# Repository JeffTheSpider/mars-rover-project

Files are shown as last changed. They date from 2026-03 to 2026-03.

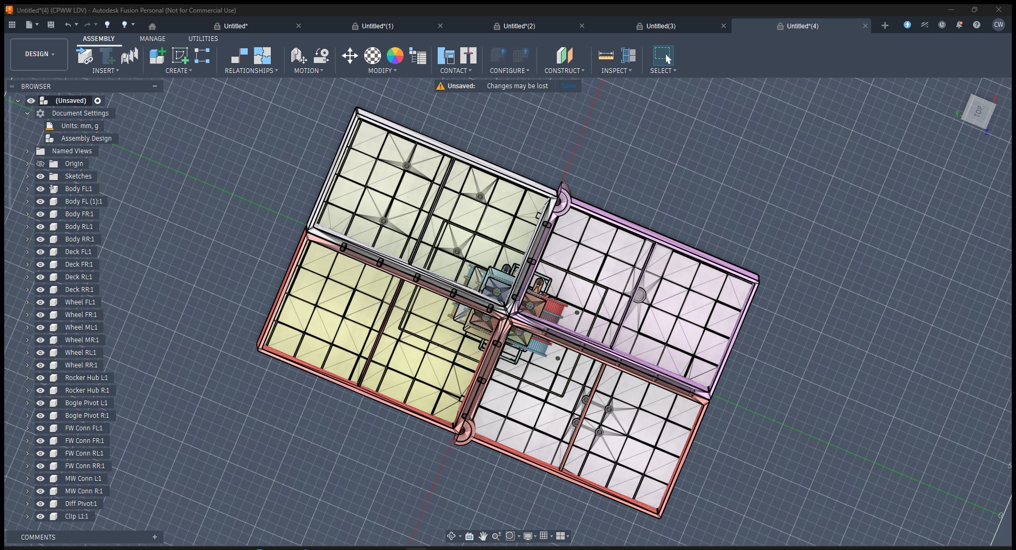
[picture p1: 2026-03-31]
3d-print/assembly_screenshot.png

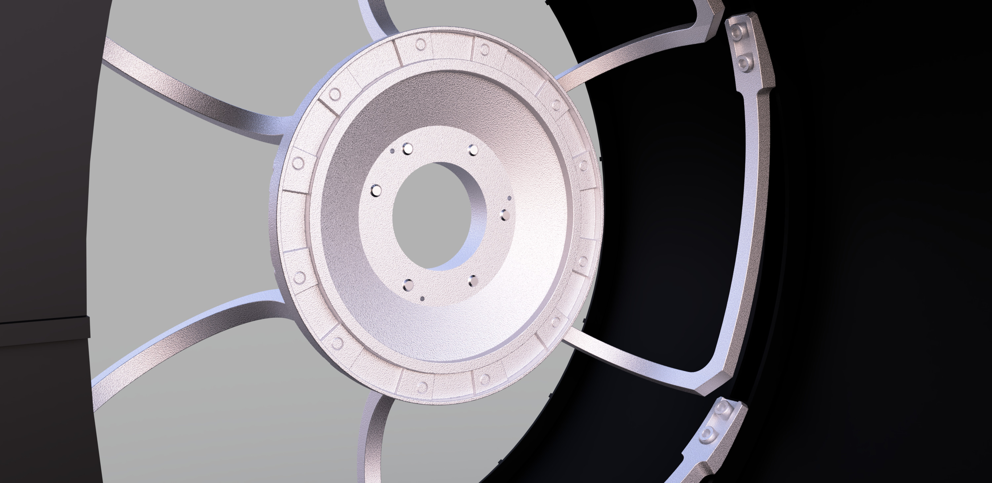
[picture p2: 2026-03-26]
cad/reference-wheels/curiosity-mars-rover-wheel-1.snapshot.2/Curiosity_Wheel_2022-Nov-08_01-30-11PM-000_CustomizedView27291791203.jpg

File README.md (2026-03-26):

# Mars Rover Garden Robot

A Mars rover-inspired outdoor robot designed for garden and park use. Features NASA-style rocker-bogie suspension, 4-wheel Ackermann steering, AI-powered autonomous navigation, and phone-based WebSocket control.

**Current status:** Phase 1 design complete. 23 print-ready STL files exported. Firmware compiles. Ready to print and build.






---

## What Is This?

A 440x260mm (0.4 scale) 3D-printed Mars rover prototype with:
- **6 wheels** with individual N20 motors
- **4-wheel steering** (Ackermann geometry, point turn, crab walk)
- **Rocker-bogie suspension** using 9x 608ZZ bearings and 8mm steel rods
- **ESP32-S3** brain with WiFi control from a phone app
- **Phone PWA** for driving, camera view, telemetry, and mission planning

Phase 1 is a working proof-of-concept. Phase 2 adds a Jetson Orin Nano for autonomous navigation with ROS2.

---

## Quick Reference

| Spec | Value |
|---|---|
| Size (Phase 1) | 440 x 260 x ~120 mm |
| Weight | ~1.25 kg |
| Power | 2S LiPo 2200 mAh (~30 min runtime) |
| Brain | ESP32-S3 DevKitC-1 N16R8 |
| Drive motors | 6x N20 100 RPM (3V-6V) |
| Steering servos | 4x SG90 micro servo |
| Motor drivers | 2x L298N dual H-bridge |
| Steering range | +/-35 degrees, min radius 397mm |
| Top speed | ~2 km/h |
| Budget | ~$102 (Phase 1 only) |
| Printer | CTC Bizer (225x145x150mm bed, PLA) |
| Print time | ~40 hours total (79 pieces from 23 part types) |

---

## How The Suspension Works

```
                    BODY (4 quadrants)
                         |
              +----------+-----------+
              |                      |
         Rocker L                Rocker R
         /       \               /       \
    Front L    Bogie L      Front R    Bogie R
                /    \                  /    \
          Middle L  Rear L       Middle R  Rear R
```

Each side has a **rocker** (front + bogie pivot) and a **bogie** (middle + rear). The two sides connect through a **differential bar** that passes through a central pivot, so when one side goes up, the other tilts down. This keeps all 6 wheels on the ground over obstacles up to 1 wheel diameter.

**Joints:** 608ZZ bearings at every pivot point (rocker, bogie, differential, steering).
**Arms:** 8mm steel rods press into printed connectors with M3 grub screws.

---

## 3D Printed Parts

23 unique part types, 79 total pieces. All designed in Fusion 360 with print-ready features (fillets, chamfers, rounded corners). All fit on a 225x145mm print bed.

### Part List

| # | Part | Size (mm) | Qty | Category | Purpose |
|---|---|---|-----|---|---|
| 1 | BearingTestPiece | 33x33x12 | 1 | Calibration | Test 608ZZ bearing press-fit |
| 2 | TubeSocketTest | 59x20x19 | 1 | Calibration | Test 8mm rod fit (3 bore variants) |
| 3 | RoverWheelV3 | 86x86x52 | 6 | Wheels | 80mm OD, 5 spokes, O-ring grooves |
| 4 | RoverTire | 86x86x44 | 6 | Wheels | TPU tire with 48 tread ribs |
| 5 | SteeringBracket | 35x30x30 | 4 | Steering | Upper steering pivot (608ZZ + hard stops) |
| 6 | SteeringKnuckle | 39x35x42 | 4 | Steering | Lower pivot + N20 motor pocket |
| 7 | SteeringHornLink | 28x8x5 | 4 | Steering | Connects SG90 horn to knuckle arm |
| 8 | ServoMount | 40x18x25 | 4 | Steering | SG90 servo pocket, bolts to connector |
| 9 | FixedWheelMount | 25x25x30 | 2 | Drivetrain | N20 mount for middle wheels (non-steered) |
| 10 | FrontWheelConnector | 35x30x30 | 4 | Suspension | Tube socket + steering + servo mounts |
| 11 | MiddleWheelConnector | 30x25x25 | 2 | Suspension | Tube socket + motor mount face |
| 12 | RockerHubConnector | 45x40x35 | 2 | Suspension | Diff bar + 2x tube sockets |
| 13 | BogiePivotConnector | 45x30x45 | 2 | Suspension | 608ZZ pivot + 3x angled tube sockets |
| 14 | DifferentialPivotHousing | 30x30x23 | 1 | Suspension | Central diff bearing + body mount |
| 15 | DifferentialLink | 20x85x6 | 2 | Suspension | Link between diff pivot and rocker hubs |
| 16 | CableClip | 11x16x5 | 12 | Suspension | Friction clip for wire routing on rods |
| 17 | BodyQuadrant | 131x226x120 | 4 | Body | Quarter of rover body shell |
| 18 | TopDeck | 133x223x10 | 4 | Body | Snap-on top panels with solar texture |
| 19 | ElectronicsTray | 120x180x18 | 1 | Body | ESP32 + L298N + LiPo mounting |
| 20 | BatteryTray | 94x42x23 | 1 | Body | 2S LiPo cradle with strap slots |
| 21 | StrainReliefClip | 18x10x12 | 10 | Accessories | Cable strain relief with snap tabs |
| 22 | FuseHolderBracket | 19x40x14 | 1 | Accessories | Inline fuse holder mount |
| 23 | SwitchMount | 30x30x5 | 1 | Accessories | Kill switch toggle mount |

### STL Files

All ready-to-slice STLs are in `3d-print/` organised by category:

```
3d-print/
  calibration/     BearingTestPiece.stl, TubeSocketTest.stl
  wheels/          RoverWheelV3.stl, RoverTire.stl
  steering/        SteeringBracket.stl, SteeringKnuckle.stl, SteeringHornLink.stl, ServoMount.stl
  drivetrain/      FixedWheelMount.stl
  suspension/      FrontWheelConnector.stl, MiddleWheelConnector.stl, RockerHubConnector.stl,
                   BogiePivotConnector.stl, DifferentialPivotHousing.stl, DifferentialLink.stl,
                   CableClip.stl
  body/            BodyQuadrant.stl, TopDeck.stl, ElectronicsTray.stl, BatteryTray.stl,
                   StrainReliefClip.stl, FuseHolderBracket.stl, SwitchMount.stl
  gcode/           (empty — for sliced gcode files)
  screenshots/     Multi-angle renders of each part
```

**Note:** BodyQuadrant and TopDeck each export as 4 variants (FL/FR/RL/RR) when run through the batch exporter in Fusion 360. The single STLs in the repo are the FL variant.

### Print Settings (PLA on CTC Bizer)

| Setting | Structural Parts | Body Panels | Small Parts |
|---|---|---|---|
| Layer height | 0.2mm | 0.2mm | 0.15mm |
| Infill | 60% | 40% | 80% |
| Perimeters | 5 | 4 | 4 |
| Support | No (designed to print flat) | No | No |
| Bed temp | 60C | 60C | 60C |
| Nozzle temp | 210C | 210C | 210C |

Print the calibration pieces first to validate bearing and tube socket fits before committing to the full print run.

---

## How It All Fits Together

### Steering Mechanism (4 corner wheels)

```
  Connector ---- 8mm rod ---- Rocker/Bogie
      |
  Steering Bracket (608ZZ bearing pivot)
      |
  Steering Knuckle (N20 motor pocket)
      |                    |
  Wheel (on N20 shaft)    Steering Arm
                              |
                          Horn Link
                              |
                          SG90 Servo (in Servo Mount)
```

The SG90 servo rotates a horn link that pushes/pulls the steering arm on the knuckle, turning it around the bearing in the bracket. The N20 motor sits inside the knuckle and directly drives the wheel. Hard stops limit rotation to +/-35 degrees.

### Middle Wheels (fixed, not steered)

```
  Middle Wheel Connector ---- 8mm rod ---- Bogie Pivot
      |
  Fixed Wheel Mount (N20 motor pocket)
      |
  Wheel (on N20 shaft)
```

### Hardware Interfaces

All mating parts use consistent hardware:
- **608ZZ bearings:** 22.15mm bore x 7.2mm deep (steering, bogie, diff pivots)
- **8mm tube sockets:** 8.2mm bore x 15mm deep + M3 grub screw
- **M3 heat-set inserts:** 4.8mm bore x 5.5mm deep (in connectors)
- **M3 through-holes:** 3.2mm clearance (in brackets and mounts)
- **N20 motor pockets:** 12.2 x 10.2 x 25mm with 4mm shaft exit
- **SG90 servo pockets:** 22.4 x 12.2 x 12mm

See [cad-dimensions-reference.md](docs/engineering/cad-dimensions-reference.md) for the full dimension table with every part.

---

## Electronics (Phase 1)

```
2S LiPo 2200mAh (7.4V)
    |
    +-- 20A blade fuse
    |
    +-- Kill switch (15mm toggle)
    |
    +-- L298N #1 (Left: FL, ML, RL motors)
    |
    +-- L298N #2 (Right: FR, MR, RR motors)
    |
    +-- ESP32-S3 DevKitC-1 (via 5V from L298N regulator)
    |
    +-- 4x SG90 servos (from ESP32 PWM pins)
```

The ESP32-S3 runs a WebSocket server. Connect with the phone PWA to drive.

See [EA-09: GPIO Pin Map](docs/engineering/09-esp32-gpio-pinmap.md) and [EA-19: Wiring](docs/engineering/19-phase1-wiring.md) for full wiring details.

---

## Repository Structure

```
Mars Rover Project/
  README.md                 <-- You are here
  CLAUDE.md                 # AI assistant project instructions

  docs/
    engineering/            # 31 engineering analyses (EA-00 to EA-30)
    plans/                  # Design doc, BOM, build guide, print strategy
    diagrams/               # 10 system diagrams (Mermaid -> SVG)
    references/             # Open-source rover research, component specs
    datasheets/             # Component datasheets

  cad/
    scripts/                # 44 Fusion 360 Python scripts
      rover_cad_helpers.py  #   Shared helper module (888 lines)
      generate_rover_params.py  # Parametric dimensions (0.4x and 1.0x)
      bearing_test_piece.py #   ... 23 part scripts
      batch_export_all.py   #   Exports all 23+ STLs in one run
      rover_assembly_v2.py  #   Full rover assembly visualisation
      ref_*.py              #   6 reference component models
    reference/              # Imported open-source CAD models
    fusion-mcp/             # Fusion 360 MCP server (AuraFriday)

  3d-print/                 # Print-ready STL files (23 types)
    calibration/            #   Test pieces
    wheels/                 #   Wheel + tire
    steering/               #   Bracket, knuckle, horn link, servo mount
    drivetrain/             #   Fixed wheel mount
    suspension/             #   7 connector/clip types
    body/                   #   Body, deck, trays, accessories
    screenshots/            #   Multi-angle part renders

  firmware/
    esp32/                  # ESP32-S3 Arduino firmware (v0.3.0)
      esp32.ino             #   Main loop, WiFi, watchdog
      config.h              #   Pin defs, geometry, timing constants
      motors.h              #   4ch L298N control + speed ramping
      steering.h            #   Ackermann / point turn / crab walk
      sensors.h             #   Battery ADC, encoders, E-stop
      rover_webserver.h     #   HTTP + WebSocket + embedded UI
      ota.h                 #   Over-the-air firmware updates
      uart_nmea.h           #   NMEA text protocol (Phase 1)
      uart_binary.h         #   COBS binary protocol (Phase 2)
      leds.h                #   5 LED status patterns
    tests/                  # 42 pytest firmware unit tests

  software/
    jetson/                 # ROS2 Humble packages (Phase 2)
      rover_bringup/        #   Launch files, config, URDF
      rover_hardware/       #   UART bridge (C++)
      rover_navigation/     #   Ackermann controller, waypoints, geofence
      rover_perception/     #   YOLO, cameras, depth
      rover_autonomy/       #   Behaviour trees
      rover_teleop/         #   WebSocket phone bridge
      rover_msgs/           #   Custom message types
    pwa/                    # Phone app (Catppuccin Mocha PWA)

  tools/                    # Utility scripts, MCP servers
```

---

## Key Documents for Understanding the Design

If you're new to this project, read these in order:

1. **[Master Design Document](docs/plans/2026-03-14-mars-rover-design.md)** -- The original design vision and spec
2. **[EA-08: Phase 1 Spec](docs/engineering/08-phase1-prototype-spec.md)** -- Exact dimensions, part list, print order
3. **[EA-25: Suspension Audit](docs/engineering/25-suspension-audit.md)** -- How the tube+connector suspension works
4. **[EA-27: Steering Design](docs/engineering/27-steering-system-design.md)** -- The 4-bar linkage steering mechanism
5. **[CAD Dimensions Reference](docs/engineering/cad-dimensions-reference.md)** -- Every part's exact dimensions and interfaces
6. **[EA-17: Build Guide](docs/engineering/17-phase1-build-guide.md)** -- Step-by-step build instructions (~14 days)
7. **[Phase 1 BOM](docs/plans/phase1-complete-bom.md)** -- Complete bill of materials (~$102)
8. **[Print Strategy](docs/plans/print-strategy.md)** -- Print order, settings, estimated times

---

## Engineering Analysis Documents

31 engineering analyses covering every aspect of the design:

| ID | Topic | What It Covers |
|----|---|---|
| EA-00 | [Master Handbook](docs/engineering/00-master-handbook.md) | Index and cross-reference to all EAs |
| EA-01 | [Suspension](docs/engineering/01-suspension-analysis.md) | Rocker-bogie geometry, NASA scaling, bearing selection |
| EA-02 | [Drivetrain](docs/engineering/02-drivetrain-analysis.md) | Torque calculations, N20 vs Chihai, L298N vs Cytron |
| EA-03 | [Power](docs/engineering/03-power-system-analysis.md) | LiPo sizing, solar, BMS, wire gauge calculations |
| EA-04 | [Compute](docs/engineering/04-compute-sensors-analysis.md) | Jetson Orin Nano, cameras, LIDAR, GPS, IMU selection |
| EA-05 | [Weight](docs/engineering/05-weight-budget.md) | Per-component mass breakdown, centre of gravity |
| EA-06 | [Cost](docs/engineering/06-cost-breakdown.md) | Phase-by-phase BOM ($2,032 total) |
| EA-07 | [Open Source](docs/engineering/07-open-source-review.md) | Sawppy + JPL rover design comparison |
| EA-08 | [Phase 1 Spec](docs/engineering/08-phase1-prototype-spec.md) | All CAD dimensions, part list, print order |
| EA-09 | [GPIO Pins](docs/engineering/09-esp32-gpio-pinmap.md) | ESP32-S3 pin assignments (20 pins Phase 1) |
| EA-10 | [Steering](docs/engineering/10-ackermann-steering.md) | Ackermann geometry, 3 modes, servo mapping |
| EA-11 | [3D Printing](docs/engineering/11-3d-printing-strategy.md) | PLA settings, CTC Bizer, heat-set insert technique |
| EA-12 | [UART Protocol](docs/engineering/12-uart-protocol.md) | NMEA-style text protocol, 18 message types |
| EA-13 | [ROS2](docs/engineering/13-ros2-architecture.md) | Node graph, Nav2, SLAM, EKF, behaviour trees |
| EA-14 | [Weatherproofing](docs/engineering/14-weatherproofing.md) | IP44/IP54 zones, cable glands (Phase 2+) |
| EA-15 | [Safety](docs/engineering/15-safety-systems.md) | E-stop, fuses, watchdog, geofence |
| EA-16 | [PWA Design](docs/engineering/16-pwa-app-design.md) | Catppuccin Mocha phone app UI/UX |
| EA-17 | [Build Guide](docs/engineering/17-phase1-build-guide.md) | Step-by-step ~14 day build timeline |
| EA-18 | [Binary UART](docs/engineering/18-binary-uart-protocol.md) | COBS + CRC-16, 460800 baud (Phase 2) |
| EA-19 | [Wiring](docs/engineering/19-phase1-wiring.md) | Complete Phase 1 wiring diagram |
| EA-20 | [CAD Prep](docs/engineering/20-cad-preparation-guide.md) | Parametric dimensions, Fusion 360 setup |
| EA-21 | [Test Procedures](docs/engineering/21-test-procedures.md) | Acceptance criteria for all subsystems |
| EA-22 | [Requirements](docs/engineering/22-requirements-specification.md) | Formal FR/PR/DIM/ELEC requirements |
| EA-23 | [Wire Harness](docs/engineering/23-wire-harness.md) | 58-wire schedule, connectors, colour codes |
| EA-24 | [Robotic Arms](docs/engineering/24-robotic-arm-study.md) | Phase 2 arm feasibility study |
| EA-25 | [Suspension Audit](docs/engineering/25-suspension-audit.md) | Tube+connector redesign, 9 bearings |
| EA-26 | [Suspension Design](docs/engineering/26-suspension-design-package.md) | Differential mechanism, DOF map |
| EA-27 | [Steering Design](docs/engineering/27-steering-system-design.md) | Horn link 4-bar, hard stops, clearance |
| EA-28 | [Integration](docs/engineering/28-systems-integration.md) | 42 cross-domain interfaces, assembly DAG |
| EA-29 | [CAD Redesign](docs/engineering/EA-29-cad-redesign.md) | Print-ready parts, shared helpers, error log |
| EA-30 | [CAD Testing](docs/engineering/EA-30-cad-testing-plan.md) | Calibration prints, tolerance adjustment |

---

## CAD Scripts

All part geometry is generated by Python scripts running in Fusion 360 (Scripts and Add-Ins). The scripts use a shared helper library (`rover_cad_helpers.py`) for consistent hardware interfaces.

### Running a script in Fusion 360

1. Open Fusion 360
2. Press **Shift+S** (Scripts and Add-Ins)
3. Select the script name (PascalCase, e.g. "SteeringBracket")
4. Click **Run**
5. The part will be created in the active design

### Batch export all STLs

Run the `BatchExportAll` script in Fusion 360. It creates a new design for each part, runs the script, exports the STL, then closes the design. Takes about 5-10 minutes for all 23+ files.

### Script naming

| Source file | Fusion 360 folder |
|---|---|
| `cad/scripts/steering_bracket.py` | `Scripts/SteeringBracket/SteeringBracket.py` |
| `cad/scripts/rover_wheel_v3.py` | `Scripts/RoverWheelV3/RoverWheelV3.py` |

Snake_case source files are deployed to PascalCase Fusion 360 script folders using the `/deploy-scripts` command.

---

## Firmware

ESP32-S3 firmware (Arduino framework). Compiles to 1045KB flash (79%), 53KB RAM (16%).

```bash
# Compile
arduino-cli compile --fqbn esp32:esp32:esp32s3 firmware/esp32/

# Upload (USB)
arduino-cli upload --fqbn esp32:esp32:esp32s3 -p COM3 firmware/esp32/
```

Features:
- 4-channel PWM motor control with speed ramping
- Ackermann steering with 3 modes (standard, point turn, crab walk)
- Arm-before-drive safety (must explicitly arm before motors will spin)
- Battery voltage monitoring with speed limiting at low voltage
- Motor stall detection
- WebSocket server with embedded Catppuccin Mocha UI
- OTA firmware updates
- 5 LED status patterns (idle, armed, driving, low battery, error)

---

## Phone App

Progressive Web App with Catppuccin Mocha dark theme. Connect via WebSocket to the ESP32-S3's IP address.

Features: D-pad driving, 3 steering modes, speed slider, E-stop button, battery telemetry, camera streams, OTA update trigger.

See `software/pwa/` and [EA-16: PWA Design](docs/engineering/16-pwa-app-design.md).

---

## Build Phases

### Phase 1 (Current) -- 0.4 Scale PLA Prototype (~$102)

3D printed PLA chassis at 40% scale. ESP32-S3 with 2x L298N motor drivers. Basic driving and phone control via WebSocket. 23 part types, 79 pieces, ~40 hours print time on CTC Bizer.

### Phase 2 -- Full Scale (~$1,631 additional)

Full-size PETG/ASA chassis with aluminium extrusion reinforcement. Adds Jetson Orin Nano Super for ROS2 autonomous navigation, LIDAR, stereo cameras, GPS, robotic arms, mini fridge, solar panels, and coffee table mode.

### Phase 3 -- Metal Chassis (~$299 additional)

Machined aluminium and steel replacing 3D printed structural components. IP54 weatherproofing for year-round outdoor operation.

---

## Phase 1 Shopping List

See [Phase 1 Complete BOM](docs/plans/phase1-complete-bom.md) for the full list. Key items:

| Item | Qty | Notes |
|---|-----|---|
| ESP32-S3 DevKitC-1 N16R8 | 1 | Main controller |
| L298N motor driver | 2 | 3 motors each |
| N20 100RPM geared motor | 6 | 3V-6V, 3mm D-shaft |
| SG90 micro servo | 4 | Steering (corner wheels only) |
| 608ZZ bearings | 12 | 9 needed + 3 spares |
| 8mm steel rod (1m) | 2 | Cut to length for suspension arms |
| M3 heat-set inserts | ~40 | 4.8mm OD x 5.5mm |
| M3x8 bolts + nuts | ~30 | Assembly fasteners |
| M2x10 bolts + nyloc nuts | 8 | Steering horn links |
| 2S LiPo 2200mAh | 1 | 7.4V, XT60 connector |
| 20A blade fuse + holder | 1 | Main power protection |
| Toggle switch (15mm) | 1 | Kill switch |
| PLA filament | ~500g | White or grey |

---

## System Diagrams

10 rendered SVG diagrams in `docs/diagrams/`:

| Diagram | Description |
|---|---|
| [system-architecture](docs/diagrams/ea28-system-architecture.svg) | High-level system block diagram |
| [mechanical-assembly](docs/diagrams/ea28-mechanical-assembly.svg) | Mechanical assembly hierarchy |
| [power-distribution](docs/diagrams/ea28-power-distribution.svg) | Power system routing |
| [signal-flow](docs/diagrams/ea28-signal-flow.svg) | Signal and data flow |
| [firmware-state](docs/diagrams/ea28-firmware-state.svg) | ESP32 firmware state machine |
| [assembly-dag](docs/diagrams/ea28-assembly-dag.svg) | Assembly dependency graph |
| [cable-routing-map](docs/diagrams/cable-routing-map.svg) | Physical cable routing paths |
| [electronics-tray-layout](docs/diagrams/electronics-tray-layout.svg) | Electronics tray component layout |

---

## Next Steps

1. Set up CTC Bizer printer (hasn't been used in years -- needs calibration)
2. Print calibration pieces (BearingTestPiece, TubeSocketTest) to validate fits
3. Order Phase 1 components (see BOM)
4. Print all parts in dependency order (see [assembly-order](docs/plans/assembly-reference.md))
5. Assemble suspension, then steering, then body
6. Wire electronics, flash firmware, test

---

## License

Personal project. Not currently open source.

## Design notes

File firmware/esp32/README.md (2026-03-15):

# ESP32-S3 Motor Controller Firmware

Low-level brain for the Mars Rover. Version 0.2.0 (Phase 1 prototype).

## Phase 1 Features
- 4-channel motor control (6 motors as 4 groups via 2× L298N)
- 4 SG90 steering servos (Ackermann, point turn, crab walk)
- WiFi web server + WebSocket for phone control
- Battery voltage monitoring (ADC with moving average)
- 2 wheel encoders (optional, interrupt-driven)
- E-stop button support
- Task watchdog (5s timeout = stop all motors)
- Speed ramping (smooth acceleration/deceleration)

## Architecture
Single translation unit (.h includes from main .ino), non-blocking state machine ticks.
Same proven pattern as Clock/Lamp ESP8266 projects.

## Files
- `esp32.ino` — Main sketch (setup, loop, WiFi, status LED)
- `config.h` — Pin definitions, constants, geometry parameters
- `motors.h` — L298N motor control (PWM + direction)
- `steering.h` — Servo control, Ackermann geometry calculations
- `sensors.h` — Battery ADC, encoder ISRs, E-stop
- `rover_webserver.h` — WiFi web UI + WebSocket for phone control
- `ota.h` — ArduinoOTA wireless firmware updates
- `uart_nmea.h` — NMEA text UART protocol for Jetson (Phase 1)
- `uart_binary.h` — COBS binary UART protocol for Jetson (Phase 2)

## Dependencies
- ESP32 Arduino Core (v3.x)
- WebSocketsServer library (by Markus Sattler)

## Build
```bash
arduino-cli compile --fqbn esp32:esp32:esp32s3 --build-property "build.extra_flags=-DBOARD_HAS_PSRAM" .
```

## Phase 2 Additions (planned)
- Binary UART protocol (EA-18, COBS + CRC-16, 460800 baud)
- PCA9685 I2C PWM driver for 14 servos
- BNO055 IMU via I2C
- 6 individual motor channels (Cytron MDD10A)
- 6 wheel encoders (hardware PCNT)
- PID speed control

## Engineering References
- EA-08: Phase 1 parts specification
- EA-09: GPIO pin map and wiring diagram
- EA-10: Ackermann steering geometry
- EA-12: UART protocol (Phase 2)

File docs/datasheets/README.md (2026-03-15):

# Component Datasheets

Download datasheets for all Phase 1 and Phase 2 components into this directory.
Naming convention: `component-name-datasheet.pdf`

## Phase 1 Components

| Component | Datasheet Source |
|---|---|
| ESP32-S3 DevKitC-1 N16R8 | [Espressif docs](https://docs.espressif.com/projects/esp-idf/en/latest/esp32s3/hw-reference/esp32s3/user-guide-devkitc-1.html) |
| L298N Dual H-Bridge | Search "L298N datasheet ST" — ST Microelectronics |
| SG90 Micro Servo | Search "SG90 datasheet" — Tower Pro |
| N20 100RPM Geared Motor | Search "N20 micro gear motor datasheet" |
| 2S LiPo 2200mAh | Battery-specific (check vendor page) |
| 608ZZ Bearings (8x22x7mm) | Standard bearing spec — any supplier |
| HC-SR04 Ultrasonic (optional) | Search "HC-SR04 datasheet" |

## Phase 2 Components

| Component | Datasheet Source |
|---|---|
| Jetson Orin Nano Super | [NVIDIA developer](https://developer.nvidia.com/embedded/jetson-orin-nano) |
| Chihai CHR-GM37-520 80RPM | Search "CHR-GM37-520 datasheet" or check AliExpress listing |
| Cytron MDD10A Motor Driver | [Cytron docs](https://www.cytron.io/p-10amp-5v-30v-dc-motor-driver-2-channels) |
| MG996R Servo | Search "MG996R datasheet" — Tower Pro |
| PCA9685 16-Ch PWM | [NXP datasheet](https://www.nxp.com/docs/en/data-sheet/PCA9685.pdf) |
| BNO055 9-DOF IMU | [Bosch datasheet](https://www.bosch-sensortec.com/products/smart-sensor-systems/bno055/) |
| BN-220 GPS Module | Search "BN-220 GPS datasheet Beitian" |
| RPLidar A1 | [Slamtec docs](https://www.slamtec.com/en/Lidar/A1) |
| 6S LiPo 20Ah | Battery-specific (check vendor page) |
| OAK-D Lite Stereo Camera | [Luxonis docs](https://docs.luxonis.com/projects/hardware/en/latest/pages/DM9095/) |
| Arducam 120° Wide Angle | [Arducam docs](https://www.arducam.com/) |
| ELP 10x Zoom Camera | Check ELP store listing |
| 100W Folding Solar Panel | Panel-specific (check vendor page) |
| MPPT Charge Controller | Controller-specific (check vendor page) |

## Notes

- Priority: download Phase 1 datasheets first (needed for build)
- Store PDFs in this directory alongside this README
- Pin diagrams and wiring references are in EA-09 and EA-19

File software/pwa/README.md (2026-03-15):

# Mars Rover Control PWA

Browser-based phone app for controlling the Mars Rover. Catppuccin Mocha dark theme matching the Hub project.

## Phase 1 Features
- D-pad touch controls (touch-and-hold = drive, release = stop)
- 3 steering modes: Ackermann, Point Turn, Crab Walk
- Speed slider (10-100%)
- E-stop button (always visible)
- Battery monitoring
- Servo trim adjustment
- LED and horn quick actions
- WebSocket connection with auto-reconnect
- Installable PWA (Add to Home Screen)
- Responsive: portrait, landscape, tablet/desktop

## Phase 2 Additions (planned)
- Live camera feeds (MJPEG via WebSocket)
- Virtual joystick (nipplejs library)
- SLAM map display
- GPS waypoint editor
- Geofence editor
- Camera selector (7 cameras)
- System health dashboard
- OTA firmware update
- Backup/restore settings

## Architecture
- **Phase 1**: PWA served by ESP32-S3 web server (port 80 HTTP, port 81 WebSocket)
- **Phase 2**: PWA served by Jetson via ROS2 web_server_node (port 8080 HTTP, port 8081 WebSocket)

## Files
```
pwa/
├── index.html          # Single page application
├── manifest.json       # PWA manifest (installable)
├── sw.js               # Service worker (network-first, v1)
├── css/
│   └── styles.css      # Catppuccin Mocha theme, responsive layout
├── js/
│   ├── app.js          # Main app logic, UI updates, section toggling
│   ├── connection.js   # WebSocket manager with exponential backoff
│   └── controls.js     # D-pad touch handling, steering modes, E-stop
├── icons/
│   ├── rover-192.png   # App icon (to be created)
│   └── rover-512.png   # App icon (to be created)
└── lib/
    ├── nipplejs.min.js # Virtual joystick (Phase 2, ~8KB)
    └── leaflet.min.js  # Map library (Phase 2, ~40KB)
```

## WebSocket Protocol
```json
// Send command (phone → rover)
{"cmd": "fwd", "speed": 50, "mode": 0}
{"cmd": "stop"}
{"cmd": "estop"}
{"cmd": "mode", "mode": 1}

// Receive status (rover → phone)
{"batt": 7.4, "pct": 78, "ml": 50, "mr": 50, "mode": 0, "estop": false}
```

## Design Language
- Theme: Catppuccin Mocha (dark)
- Accent: Mars Red (#f38ba8)
- Secondary: Sand (#f9e2af)
- Font: Plus Jakarta Sans (headings), system sans (body)
- Tap targets: 48px minimum
- Touch-optimised (touchstart/touchend, no click)

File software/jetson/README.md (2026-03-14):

# Jetson Orin Nano Software

High-level brain for the Mars Rover. Runs ROS2 Humble on Ubuntu.

## Components
- **ROS2 nodes**: Navigation, SLAM, sensor fusion, camera management
- **AI pipeline**: YOLO v8 object detection, depth processing
- **Web server**: Express/Flask, WebSocket for phone control, WebRTC for camera streams
- **Camera manager**: 7 camera feeds, 360-degree stitching, zoom control
- **Arm controller**: Inverse kinematics, gesture library
- **Anti-theft**: Geofence, motion detect, GPS tracking, alarm

## Communication
UART to ESP32-S3 at 115200 baud, binary packet protocol.

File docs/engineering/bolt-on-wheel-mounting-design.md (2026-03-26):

# Bolt-On Wheel Mounting System — Design Decision Document

**Date**: 2026-03-26
**Status**: Implemented
**References**: EA-25 (Suspension Audit), EA-26 (Suspension Design), EA-30 (CAD Testing)

## 1. Problem Statement

The V5 Curiosity wheel (80mm OD, 6 spokes) and reference suspension (43 parts at 0.4x) are both ready, but the interface between them has three incompatibilities:

| Issue | Detail | Impact |
|---|---|---|
| Reference motor shaft coupler OD | 20mm at 0.4x | 608ZZ bearing (22mm OD) won't fit inside it |
| Reference coupler bore | 2.5mm at 0.4x | N20 D-shaft is 3mm, doesn't fit |
| No bolt holes | Press-fit only design | No secure wheel-to-structure attachment |

## 2. Solution Overview

Replace reference couplers with our parametric wheel connectors, add matching bolt holes to V5 wheel hub, and introduce 608ZZ bearing + 8mm axle interface.

```
SUSPENSION ARM (8mm steel tube)
        |
[PARAMETRIC CONNECTOR] — tube socket + heat-set inserts
        |
[FIXED WHEEL MOUNT] — N20 motor clip (middle wheels)
    or [STEERING KNUCKLE] — N20 motor clip + steering pivot (front/rear)
        |
  [608ZZ BEARING] — decouples wheel loads from motor
        |
  [8mm AXLE STUB] — through bearing into wheel bore
        |
  [V5 WHEEL] — 4x M3 bolts on 20mm BCD
```

## 3. Design Decisions

### DD-01: 4x M3 on 20mm BCD (over 2x Linear 16mm)

**Decision**: Changed from 2x M3 heat-set inserts on 16mm linear spacing to 4x M3 on 20mm bolt circle diameter.

**Rationale**:
- **Equal load distribution**: 4 bolts at 90-degree intervals distribute clamping force evenly, preventing hub rocking
- **Self-centering**: BCD pattern naturally centers the wheel on the connector face
- **Torque resistance**: 4-point pattern resists rotational forces better than 2-point
- **Redundancy**: If one bolt loosens, 3 remaining bolts still hold (2-bolt pattern has no redundancy)

**Clearance analysis** (verified by alignment script):
- Inner clearance (bolt edge to bore edge): 4.3mm
- Outer clearance (bolt edge to hub face edge): 2.4mm
- Spoke root clearance: 0.4mm (acceptable — bolts pass between spokes, not through them)

**Trade-offs**:
- 4 bolts vs 2 bolts: More hardware (24 vs 12 bolts total), longer assembly time
- BCD vs linear: Slightly more complex manufacturing, but better engineering practice
- 20mm BCD vs larger: 20mm chosen as optimal fit — smaller risks spoke collision, larger risks hub edge breakout

### DD-02: Button Head Bolts (over Socket Cap Head)

**Decision**: Use M3x10 button head bolts (ISO 7380) instead of socket cap head (ISO 4762).

**Rationale**:
- Button head height: ~1.65mm (ISO) vs cap head: 3mm — lower profile
- Sits flush inside wheel hub cavity without interfering with spokes
- Sufficient strength for PLA-on-PLA clamping loads (~200g per wheel)
- Allen key socket for positive drive

### DD-03: 608ZZ Bearing at Each Wheel

**Decision**: Add 608ZZ bearing between wheel connector and wheel, transferring radial loads from motor shaft to structure.

**Rationale**:

| Factor | With 608ZZ | Without (direct D-shaft) |
|---|---|---|
| Radial load on motor | Near zero | ~210g per wheel |
| Shaft stiffness | 8mm axle (I=201mm^4) | 3mm D-shaft (I=3.98mm^4) = 50x less |
| Motor bearing life | Years | Months (constant side load) |
| Wheel wobble | None (precision bearing) | Increasing over time |
| Impact protection | Bearing absorbs hits | Motor gearbox takes damage |
| Cost | $0.50 each, $3 total | $0 |

**Trade-offs**:
- Requires 6 additional 608ZZ bearings (total project: 9 pivot + 6 wheel = 15)
- Original purchase was 12 bearings (9 allocated + 3 spare) — need 3 more
- Adds ~1mm to wheel-to-connector stack-up (bearing width 7mm)

### DD-04: 8mm Axle Stubs

**Decision**: Use 8mm diameter x 15mm steel axle stubs through 608ZZ bearings, driven by N20 motor via D-shaft coupler.

**Rationale**:
- 8mm matches 608ZZ inner bore exactly (standard sizing)
- Bending stiffness: I = pi*d^4/64. 8mm: 201mm^4 vs 3mm: 3.98mm^4 = **50x stiffer**
- V5 wheel hub bore is 8.2mm — perfect 0.1mm clearance fit for 8mm axle
- 15mm length provides ~7mm in bearing + ~3mm through connector + ~5mm into wheel bore

### DD-05: Through-Bolt Direction (Wheel Side Into Connector)

**Decision**: Bolts insert from the wheel side (through clearance holes in hub) into heat-set inserts in the connector.

**Rationale**:
- Bolt heads are recessed inside the wheel hub cavity — no external protrusions
- Heat-set inserts in PLA connector provide threaded engagement in the structural part
- Wheel removal is straightforward: unscrew 4 bolts, slide wheel off axle
- Alternative (bolts from connector side) would require reaching through the suspension structure

## 4. Component Modifications

### V5 Wheel Hub (CuriosityV5_Complete.stl, CuriosityV5_HubSpokes.stl)

**Change**: Added 4x M3 clearance holes (3.2mm dia) through hub back face plate.

**Method**: manifold3d boolean subtraction (trimesh mesh -> manifold3d Manifold -> subtract cylinders -> export)

**Script**: `cad/scripts/add_wheel_bolt_holes.py`

**Verification**:
- 4/4 holes verified in both STL files
- Hole diameter: 3.2mm (M3 clearance)
- Hole depth: full hub face thickness (~4.8mm)
- Center bore intact at 8.2mm
- Bolt inner edge to bore outer edge: 3.4mm clearance
- Original files backed up as `*_pre_boltholes.stl`

### Middle Wheel Connector (middle_wheel_connector.py)

**Change**: Bottom face bolt pattern changed from 2x M3 heat-set inserts on 16mm linear spacing to 4x M3 on 20mm BCD.

**Script changes**:
- Added imports: `WHEEL_BCD`, `WHEEL_BOLT_COUNT`, `make_heat_set_bcd`
- Replaced `make_heat_set_pair(spacing=1.6)` with `make_heat_set_bcd(bcd=2.0, count=4)`

### Front/Rear Wheel Connector (front_wheel_connector.py)

**Change**: Steering bracket mount changed from 2x M3 linear to 4x M3 on 20mm BCD for interface standardization.

### Fixed Wheel Mount (fixed_wheel_mount.py)

**Change**: Through-hole pattern changed from 2x M3 linear 16mm to 4x M3 on 20mm BCD to match connector inserts.

### Shared Helpers (rover_cad_helpers.py)

**Added**:
- `make_heat_set_bcd()` function — places N heat-set pockets on a bolt circle
- `M3_CLEARANCE` constant (1.6mm radius = 3.2mm dia)
- `WHEEL_BCD` constant (2.0 cm = 20mm)
- `WHEEL_BOLT_COUNT` constant (4)

## 5. New Hardware Components

### M3x10 Button Head Bolts
- **Spec**: ISO 7380 M3x10mm, A2 stainless
- **Head**: 5.5mm OD x 1.65mm (modeled as 3mm for visual clarity)
- **Qty**: 24 (4 per wheel x 6 wheels)
- **STL**: `3d-print/hardware/M3x10_ButtonHead.stl` (visualization only)

### 8mm Axle Stubs
- **Spec**: 8mm dia x 15mm, mild steel
- **Source**: Cut from 8mm steel rod stock
- **Qty**: 6 (one per wheel)
- **STL**: `3d-print/hardware/8mm_AxleStub.stl` (visualization only)

### Additional 608ZZ Bearings
- **Spec**: 608ZZ (8x22x7mm), ABEC-1 or better
- **Qty**: 6 at wheels + 9 at pivots = 15 total (was 12 purchased, need 3 more)
- **STL**: `3d-print/hardware/608ZZ_Bearing.stl` (visualization only)

## 6. Verification Results

Full alignment check performed by `wheel_mounting_assembly.py`:

| Check | Value | Threshold | Result |
|---|---|---|---|
| Bolt inner clearance (all 4) | 4.3mm | >1.0mm | PASS |
| Bolt outer clearance (all 4) | 2.4mm | >1.0mm | PASS |
| Spoke clearance (all 4) | 0.4mm | >0.0mm | PASS |
| Axle-bearing clearance | 0.0mm | >=0.0mm | PASS |
| Axle-bore clearance | 0.1mm | >0.0mm | PASS |
| Bearing seat wall thickness | 4.0mm | >=3.0mm | PASS |

Assembly GLB exported to `temp/wheel_mounting_assembly.glb` for visual inspection.

## 7. Updated Parts List

### Wheel Mounting Hardware (per wheel)
| Item | Qty | Spec |
|---|-----|---|
| M3x10 button head bolt | 4 | ISO 7380, A2 stainless |
| M3 heat-set insert | 4 | 4.8mm bore x 5.5mm, brass knurled |
| 608ZZ bearing | 1 | 8x22x7mm |
| 8mm axle stub | 1 | 15mm long, mild steel |

### Project Bearing Count Update
| Use | Qty | Subtotal |
|-----|-----|---|
| Rocker pivots | 2 | 2 |
| Bogie pivots | 2 | 4 |
| Differential pivot | 1 | 5 |
| Steering pivots | 4 | 9 |
| **Wheel axles** | **6** | **15** |
| Spares | 3 | **18** |

**Purchase update**: Originally 12 bearings purchased (9+3 spare). Now need 18 total (15+3 spare). **Order 6 more 608ZZ bearings.**

## 8. Lessons Learned (For Future Skill Development)

### L-01: manifold3d for Boolean Operations on Non-Watertight Meshes
- trimesh boolean requires watertight meshes, but reference STLs often aren't
- manifold3d (`pip install manifold3d`) handles non-manifold meshes natively
- Pattern: `trimesh.load() -> manifold3d.Manifold(Mesh(verts, faces)) -> boolean ops -> back to trimesh`
- manifold3d API: `cylinder(height, radius_low, radius_high)`, `translate([x,y,z])`, subtraction with `-`

### L-02: Bolt Pattern Standardization
- Standardizing all mounting interfaces to the same BCD simplifies assembly and reduces error
- BCD patterns are self-centering (unlike linear bolt patterns)
- Always verify bolt clearance to adjacent features (bore, spokes, edges) before committing

### L-03: Assembly Visualization for Interface Verification
- Building assembly in trimesh catches alignment issues before printing
- Color-coding by component type (wheel=dark, bolt=steel, bearing=silver) aids visual inspection
- JSON verification report provides auditable proof of clearance checks

### L-04: Bearing-Decoupled Motor Mounting
- Direct motor shaft to wheel is acceptable for prototype but damages motors long-term
- 608ZZ bearings at $0.50 each are cheap insurance for motor longevity
- The design pattern: motor -> coupler -> axle through bearing -> wheel

### L-05: Parameter Traceability Through Shared Constants
- Adding constants to `rover_cad_helpers.py` (WHEEL_BCD, M3_CLEARANCE) ensures all scripts use the same values
- Every script that creates bolt holes imports from the same source
- Changes to the bolt pattern only need updating in one place

## 9. Files Created/Modified

| File | Action | Description |
|---|---|---|
| `cad/scripts/add_wheel_bolt_holes.py` | Created | Adds M3 bolt holes to wheel STLs via manifold3d |
| `cad/scripts/wheel_mounting_assembly.py` | Created | Builds assembly, generates hardware meshes, verifies alignment |
| `cad/scripts/rover_cad_helpers.py` | Modified | Added make_heat_set_bcd, M3_CLEARANCE, WHEEL_BCD constants |
| `cad/scripts/middle_wheel_connector.py` | Modified | 2x linear -> 4x BCD bolt pattern |
| `cad/scripts/front_wheel_connector.py` | Modified | 2x linear -> 4x BCD steering mount |
| `cad/scripts/fixed_wheel_mount.py` | Modified | 2x linear -> 4x BCD through-holes |
| `3d-print/wheels/CuriosityV5_Complete.stl` | Modified | Added 4x M3 bolt holes |
| `3d-print/wheels/CuriosityV5_HubSpokes.stl` | Modified | Added 4x M3 bolt holes |
| `3d-print/hardware/M3x10_ButtonHead.stl` | Created | Visualization mesh |
| `3d-print/hardware/8mm_AxleStub.stl` | Created | Visualization mesh |
| `3d-print/hardware/608ZZ_Bearing.stl` | Created | Visualization mesh |
| `temp/wheel_mounting_assembly.glb` | Created | Full assembly visualization |
| `temp/wheel_mounting_verification.json` | Created | Alignment check results |
| `docs/engineering/bolt-on-wheel-mounting-design.md` | Created | This document |

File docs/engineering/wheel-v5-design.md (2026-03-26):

# Wheel V5 Design — Curiosity-Inspired Adaptation

**Document**: Wheel Component Design Specification
**Version**: 5.0
**Date**: 2026-03-26
**Status**: Active — replaces V3 (single-piece) and V4 (scripted two-piece)
**Reference Model**: `cad/reference-wheels/curiosity-mars-rover-wheel-1.snapshot.2/Curiosity Wheel v25.f3d`

---

## 1. Design Decision

We are adopting the downloaded Curiosity Mars Rover wheel CAD model (Curiosity Wheel v25, Fusion 360) as the **reference design** for our wheel system. This replaces the previous scripted approaches (V3 single-piece, V4 spiral-spoke hub).

**Why**: The Curiosity model has professional-quality curved S-spokes, authentic chevron grousers, rectangular lightening holes, and a proper hub/spoke/tread architecture that would take weeks to recreate parametrically. We will scale and adapt it rather than reinvent it.

### Version History

| Version | Approach | Status |
|---|---|---|
| V1 | Simple cylinder + flat spokes | Superseded |
| V2 | Improved spokes, single piece | Superseded |
| V3 | Revolve profile + arc spokes, single piece | Superseded |
| V4 | Two-piece (scripted hub + tire bands + beadlock) | Superseded by V5 |
| **V5** | **Curiosity reference model, scaled + adapted** | **Active** |

---

## 2. Curiosity Wheel — Original Analysis

### 2.1 Model Structure (from IGES import)

| Component | Original Size | Count | Notes |
|---|---|---|---|
| **Tread ring** | 448mm OD x 404mm wide | 1 (3 bodies) | Chevron grousers + lightening holes |
| **Hub disc** | 175mm OD x 30mm thick | 1 | Central bore + radial ribs + bolt bosses |
| **Spokes** | 218 x 138 x 103mm | 6 | Curved S-profile titanium |
| **Screws** | M5 SHCS, 16mm long | 30 | 5 per spoke (2 at tread, 2 at hub, 1 mid) |

### 2.2 Key Radii (from model)

| Feature | Radius | Diameter |
|---|---|---|
| Tread OD | 224.0mm | 448.0mm |
| Tread ID (inner skin) | 210.4mm | 420.8mm |
| Hub OD | 87.5mm | 175.0mm |
| Hub bore | 26.0mm | 52.0mm |
| Spoke inner attach | 67.5mm | 135.0mm |
| Spoke outer attach | ~204mm | ~408mm |

### 2.3 Tread Geometry

The tread ring (Body1: 797 faces, 2335 edges) has:
- **Chevron grousers**: V-shaped treads on the outer surface, angled for directional grip
- **Rectangular lightening holes**: Cut through the cylindrical skin between grousers, arranged in circumferential rows — provide compliance (flex) and weight reduction
- **Structural ribs**: Thickened bands between hole rows maintain hoop strength
- **Two small marker bodies**: Body2 (3.0mm) and Body3 (3.0mm) — likely JPL Morse code tread marks (real Curiosity stamps "JPL" in its tracks)

---

## 3. Curiosity Tread Material Analysis — NO RUBBER

### 3.1 Real Curiosity Wheel Construction

**The real Curiosity rover wheels contain ZERO rubber.** The entire wheel — tread, skin, and grousers — is machined from a single block of **7075-T7351 aluminium alloy**.

| Property | Curiosity Wheel |
|---|---|
| **Tread material** | Machined aluminium (7075-T73) |
| **Skin thickness** | 0.75mm (thinnest machinable) |
| **Grouser height** | 7.5mm |
| **Grouser spacing** | 15 degrees apart (24 grousers) |
| **Spoke material** | Titanium (curved, springy) |
| **Hub material** | Aluminium |
| **Fasteners** | Stainless steel socket head cap screws |
| **Rubber/polymer** | **NONE** |

### 3.2 Why No Rubber on Mars?

1. **Temperature**: Mars surface ranges -140C to +30C. Rubber becomes brittle glass below -60C
2. **UV radiation**: No ozone layer on Mars — UV destroys rubber in weeks
3. **Vacuum outgassing**: Low atmospheric pressure (0.6 kPa) causes rubber to outgas volatiles
4. **Weight**: Rubber adds mass without benefit — Mars gravity is 38% of Earth
5. **Grip not needed**: On Mars regolith, the thin aluminium skin *floats* on loose sand while grousers dig in for traction. Rubber friction is irrelevant on granular terrain

### 3.3 Curiosity Wheel Damage History

Despite the all-metal construction, Curiosity's wheels suffered significant damage:
- **Within 1 year**: Visible punctures and tears in the 0.75mm skin
- **Cause**: Sharp Mars rocks concentrated stress on the thin skin between grousers
- **Lesson for Perseverance**: Thicker skin (1.0mm), narrower but taller (52.5cm x 20cm), redesigned tread to reduce stress concentrations

### 3.4 Implications for Our Rover

Our rover operates on **Earth** (garden/park), not Mars. Key differences:

| Factor | Mars (Curiosity) | Earth (Our Rover) |
|---|---|---|
| Surface | Regolith, sharp rocks | Grass, paths, gravel, mud |
| Gravity | 3.7 m/s2 | 9.8 m/s2 |
| Temperature | -140 to +30C | -5 to +35C (UK) |
| Traction need | Low (light rover, loose soil) | High (heavier rover, varied surfaces) |
| Material | Machined aluminium | 3D printed PLA |
| Wheel count | 6 (rocker-bogie) | 6 (rocker-bogie) |

**Conclusion**: We **do** benefit from a traction surface on Earth. Options:

1. **PLA grousers only** (simplest) — Curiosity-style chevrons printed integral with tread
2. **Rubber O-ring bands** in grooves (our existing plan) — adds grip on hard surfaces
3. **Rubber spray coating** (Plasti Dip) — thin rubber layer on tread surface
4. **Interchangeable tire bands** (V4 concept) — snap-on PLA bands with different tread patterns

**Recommendation**: Option 1 (integral PLA chevron grousers) as the primary design, matching the Curiosity aesthetic. If traction is insufficient on smooth surfaces during testing, add rubber O-ring bands in circumferential grooves.

---

## 4. V5 Adaptation Plan

### 4.1 Scaling

| Dimension | Curiosity (original) | V5 (0.4 scale) | Method |
|---|---|---|---|
| Tread OD | 448mm | **80mm** | Scale 0.1786x |
| Tread width | 404mm | **40mm** | Scale 0.099x (adjusted to match project spec) |
| Hub OD | 175mm | **31mm** | Scale 0.1786x |
| Hub bore | 52mm | **8.1mm** (N20 D-shaft clearance) | Adapted for motor |
| Skin thickness | 0.75mm | **2.0mm** (PLA minimum) | DFM adapted |
| Grouser height | 7.5mm | **3.0mm** | Project spec (EA-08) |

**Note**: Width does not scale proportionally — Curiosity's wheel is nearly as wide as it is tall. Our rover needs 40mm width per EA-08 spec, giving a more conventional aspect ratio.

### 4.2 Structural Adaptations for PLA

The Curiosity wheel is machined aluminium + titanium. PLA printing requires:

| Feature | Curiosity | V5 PLA Adaptation |
|---|---|---|
| Spokes | Separate titanium, bolted | **Integral with hub** (single print) |
| Skin thickness | 0.75mm | **2.0mm minimum** (PLA wall requirement) |
| Lightening holes | Through-skin rectangular | **Decorative only** — optional, may weaken PLA |
| Grousers | Machined integral | **Printed integral** (same approach) |
| Hub-to-axle | Bolted flange | **D-shaft bore** (3.1mm) + M3 grub screw |
| Spoke-to-tread | 30x M5 bolts | **Printed integral** |
| Spoke count | 6 (titanium) | **6** (PLA, thicker cross-section) |

### 4.3 What We Keep from Curiosity

1. **S-curved spoke profile** — the iconic Curiosity look
2. **6 spokes** at 60-degree intervals
3. **Chevron grouser pattern** on tread surface
4. **Hub disc** with radial rib reinforcement between spokes
5. **Overall proportions** — hub-to-tread ratio, spoke curvature

### 4.4 What We Change

1. **Single piece**: Hub + spokes + tread ring printed as one PLA part (no bolted assembly)
2. **Motor bore**: Replace 52mm central bore with 8.1mm N20 D-shaft + boss
3. **Wall thickness**: All walls minimum 2.0mm for PLA strength
4. **No lightening holes**: Skin stays solid for PLA stiffness (optional cosmetic holes in Phase 2)
5. **Width**: 40mm (not 404mm scaled) — per project specification
6. **Beadlock option**: Retained from V4 if interchangeable tire bands are desired later
7. **Grub screw**: M3 radial set screw in hub boss to lock on D-shaft

### 4.5 Two Approaches Available

#### Approach A: Scale the Reference Model (Manual in Fusion 360)
1. Open `Curiosity Wheel v25.f3d` in Fusion 360
2. Combine spoke + hub + tread into single body
3. Scale to 0.1786x
4. Modify hub bore for N20 shaft
5. Adjust wall thicknesses
6. Export as STL

**Pros**: Fastest path, preserves all Curiosity detail
**Cons**: Non-parametric, manual editing, hard to version control

#### Approach B: Recreate in Script Using Curiosity as Reference
1. Write `rover_wheel_hub_v5.py` inspired by Curiosity geometry
2. Use measurements from reference model for spoke curves
3. Parametric — can be regenerated, version controlled, batch exported

**Pros**: Consistent with project workflow, parametric, reproducible
**Cons**: May not capture all Curiosity nuance, more development time

**Recommendation**: Approach A for initial prototype (get it printed quickly), then Approach B for the final production script if dimensional changes are needed.

---

## 5. Traction Strategy

### 5.1 Phase 1: Printed PLA Grousers (Curiosity-Style)

The primary tread pattern follows Curiosity's chevron design:
- 12-24 chevron grousers (scaled from Curiosity's 24)
- 3mm tall (per EA-08 spec)
- V-shaped for directional grip and self-cleaning
- Printed integral with tread ring

Expected performance:
- **Grass**: Good — grousers dig into soft surface
- **Gravel/paths**: Good — grousers grip irregularities
- **Smooth concrete**: Poor — PLA-on-concrete has low friction
- **Wet surfaces**: Poor — no rubber compliance

### 5.2 Phase 1 Enhancement: Rubber O-Ring Bands

If PLA traction is insufficient on smooth/wet surfaces:
- Machine 2-3 circumferential grooves in tread between grousers
- Fit standard rubber O-rings (e.g., 76mm ID x 3mm cross-section)
- O-rings provide rubber contact patch without full tire change
- Cost: ~$5 for a bag of O-rings

### 5.3 Phase 2: Interchangeable Tire Bands (Retained from V4)

The V4 tire band concept remains available for Phase 2:
- Hub has 70mm OD tire seat + beadlock ring mounting
- Snap-on PLA tire bands with different tread patterns (Mars, smooth, offroad, paddle)
- Allows seasonal tread changes

---

## 6. Bill of Materials — Wheel Assembly (V5)

### Per Wheel
| Item | Qty | Material | Notes |
|---|-----|---|---|
| Wheel (hub+spokes+tread) | 1 | PLA | Single print, Curiosity-inspired |
| M3 x 5mm grub screw | 1 | Steel | Locks wheel to D-shaft |

### Per Rover (6 wheels)
| Item | Qty | Notes |
|---|-----|---|
| Wheels | 6 | ~15g PLA each, ~3hr print each |
| M3 grub screws | 6 | From Phase 1 hardware kit |
| Rubber O-rings (optional) | 12-18 | 76mm ID x 3mm, if needed for traction |

---

## 7. Print Specifications

| Parameter | Value |
|---|---|
| **Orientation** | Hub face down (spokes print upward) |
| **Material** | PLA |
| **Layer height** | 0.2mm |
| **Infill** | 50% gyroid |
| **Perimeters** | 4 |
| **Supports** | Yes — for spoke overhangs |
| **Bed adhesion** | Brim (8mm) |
| **Estimated time** | ~3 hours per wheel |
| **Estimated weight** | ~15g per wheel |
| **Bed fit** | 80mm diameter — well within 225x145mm |

---

## 8. Interface Compatibility

The V5 wheel maintains all existing interfaces:

| Interface | Dimension | Mates With |
|---|---|---|
| D-shaft bore | 3.1mm (0.1mm clearance on 3mm shaft) | N20 motor |
| Hub boss OD | ~12mm | Fixed wheel mount bore |
| Grub screw | M3, radial through hub boss | Locks on D-shaft flat |
| Wheel OD | 80mm | Ground contact, clearance envelope |
| Wheel width | 40mm | Fixed wheel mount width slot |

---

## 9. File Inventory

### Reference Model
| File | Size | Format |
|---|---|---|
| `cad/reference-wheels/.../Curiosity Wheel v25.f3d` | 4.2MB | Fusion 360 native (parametric) |
| `cad/reference-wheels/.../Curiosity Wheel v25.iges` | 12.7MB | IGES (importable) |
| `cad/reference-wheels/.../Curiosity Wheel v25.obj` | 44.9MB | OBJ mesh |
| `cad/reference-wheels/.../Curiosity Wheel v25.sat` | 19.1MB | ACIS SAT |

### Previous Scripts (retained for reference / alternative)
| Script | Purpose | Status |
|---|---|---|
| `rover_wheel_hub_v4.py` | Scripted spiral spoke hub | Available (V4) |
| `rover_tire_mars.py` | Mars chevron tire band | Available (V4 tire) |
| `rover_tire_smooth.py` | Smooth indoor tire band | Available (V4 tire) |
| `rover_tire_offroad.py` | Deep lug tire band | Available (V4 tire) |
| `rover_tire_paddle.py` | Paddle sand tire band | Available (V4 tire) |
| `rover_beadlock_ring.py` | Tire retention ring | Available (V4 accessory) |

### V5 Target
| File | Purpose | Status |
|---|---|---|
| `rover_wheel_v5.py` or manual F360 | Curiosity-adapted single-piece wheel | **To be created** |

---

## 10. Sources

- [NASA Mars 2020 Rover Wheels](https://mars.nasa.gov/mars2020/spacecraft/rover/wheels/)
- [NASA's Memory Wheels — USC Viterbi](https://illumin.usc.edu/nasas-memory-wheels/)
- [How NASA Reinvented The Wheel — Medium](https://medium.com/predict/how-nasa-reinvented-the-wheel-83bbc8f528ed)
- [Diagram of a Curiosity Wheel — Planetary Society](https://www.planetary.org/space-images/diagram-of-a-curiosity-wheel)
- [Metal Tires for Mars — Space.com](https://www.space.com/39305-metal-tires-for-mars-rovers.html)
- [What material are Curiosity's wheels? — Quora](https://www.quora.com/What-material-are-NASAs-Curiosity-rovers-wheels-made-of-Would-they-have-lasted-longer-if-they-were-mass-of-car-tyre-rubber)
- [Leo Rover Blog — Different Shades of Wheel](https://www.leorover.tech/post/different-shades-of-wheel)

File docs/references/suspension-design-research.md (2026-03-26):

# Rocker-Bogie Suspension Design Research

**Date:** 2026-03-26
**Purpose:** Find open-source rocker-bogie designs to study and adapt components from.

---

## Our Current Suspension Specs

- 0.4 scale (body 440×260mm)
- 608ZZ bearings × 9 (2 rocker + 2 bogie + 1 diff pivot + 4 steering)
- 8mm steel rods as suspension arms, inserted into printed connectors
- Tube socket: 8.2mm bore, 15mm depth, M3 grub screw retention
- Through-bar differential mechanism (300mm 8mm steel rod)
- Track width 280mm, wheelbase 360mm
- N20 motors (12×10×24mm), SG90 servos

---

## Complete Suspension Systems Compared

### 1. Sawppy Rover ★★★ (MOST RELEVANT)
- **URL:** https://github.com/Roger-random/Sawppy_Rover
- **License:** MIT
- **Format:** Onshape + 23 STL files
- **Architecture:** 8mm steel shafts + 15mm aluminium extrusions + 608ZZ bearings (30!)
- **Differential:** Through-bar with turnbuckle ball joints (M3) connecting to rockers
- **Connectors:** Bolt clamp around 15mm extrusion, set screws in heat-set inserts
- **Key dimensions:** Diff bar 300mm, rocker pivot 84mm, bogie pivot 66.5mm, steering shaft 61mm, wheel axle 50mm

**CRITICAL LESSONS:**
1. **Diff bar BENT under load** — needed printed DiffBrace (upper + lower clamp). Our 8mm bar may have same issue.
2. **Heat-set insert variability** — different manufacturers = different bore sizes = widespread build failures. We must validate 4.8mm × 5.5mm spec with test print.
3. **E-clip shaft retention** as alternative to grub screws (more secure)
4. **Hex wrench shaft** variant prevents rotation (clever)

### 2. jakkra Mars-Rover ★★★
- **URL:** https://github.com/jakkra/Mars-Rover
- **License:** MIT
- **Format:** Fusion 360 .f3z/.f3d (directly importable!)
- **Architecture:** 25mm PVC pipes + 608ZZ + SKF 6005 bearings
- **Motors:** 12V 60RPM DC motors, MG996R servos
- **Value:** Import .f3z as reference overlay in our Fusion 360 assembly

### 3. NASA-JPL Open Source Rover ★★☆
- **URL:** https://github.com/nasa-jpl/open-source-rover
- **License:** Apache 2.0
- **Format:** Onshape
- **Architecture:** goRail aluminium extrusions, flanged bearings (8×14×5mm, NOT 608ZZ)
- **Differential:** Pivot bar + 45° brackets + turnbuckles
- **Value:** Best documentation of any project. Study geometry ratios and bogie joint spacing.
- **Key technique:** Asymmetric spacers (4mm + 6mm) on bogie pivot prevent lateral flex

### 4. ESA ExoMy ★☆☆
- **URL:** https://github.com/esa-prl/ExoMy
- **License:** GPL-3.0
- **Architecture:** Triple-bogie (NOT rocker-bogie), fully 3D-printed, servo-direct-drive
- **Value:** Different suspension philosophy. Study their 3 steering modes (same as ours).

### 5. HowToMechatronics Perseverance ★★☆
- **URL:** https://howtomechatronics.com/projects/diy-mars-perseverance-rover-replica-with-arduino/
- **License:** Paid STL ($3), personal use only
- **Architecture:** 20mm aluminium profiles, M8 bolt pivots, rod-end ball joints
- **Key technique:** Rod-end ball joints on differential — elegant, adjustable
- **Key dimension:** 20mm gap between diff link and rod end = level chassis

---

## Differential Mechanism Comparison

| Type | Project | Our Compatibility | Notes |
|---|---|---|---|
| **Through-bar + turnbuckle** | Sawppy | HIGH — same bar, different links | Bar bends! Need brace. |
| **Through-bar direct coupling** | Our design | Current approach | Simplest, but must prevent bending |
| **Rod-end ball joints** | HowToMechatronics | Possible upgrade | More robust, adjustable |
| **45° bracket + turnbuckle** | JPL OSR | LOW — aluminium extrusion based | Study geometry only |
| **Bevel gear** | Real Spirit/Opportunity | LOW — complex to print | Phase 3 maybe |
| **Magnetic pivot** | Morethan3D | NO — not robust for outdoor | Creative but impractical |
| **No differential** | Fishbone Mini Rover | Fallback only | Body tilts uncontrolled |

---

## Connector Design Comparison

| Approach | Project | Tube/Rod | Retention | Our Assessment |
|---|---|---|---|---|
| **Extrusion bolt clamp** | Sawppy | 15mm Al extrusion | M3 bolts + channel nuts | Different from ours, very strong |
| **Socket + grub screw** | Our design | 8mm steel rod | M3 grub in heat-set insert | Good compromise, validate with test print |
| **PVC pipe + screw** | jakkra | 25mm PVC | Screw-through | Too large for 0.4 scale |
| **Bolt-through pivot** | Fishbone/ROVER-X | M3/M5 screw | Nylon lock nut | Too simple, will wear |
| **Set screw + E-clip** | Sawppy (shafts) | 8mm shaft | Set screw + E-clip groove | Consider as alternative to grub screw |

---

## Steering Knuckle Comparison

| Design | Bearings | Shaft | Servo Linkage | Our Assessment |
|---|---|---|---|---|
| **Sawppy** | 2× 608ZZ (top+bottom) | 8mm | Direct servo on shaft | More robust than ours (dual bearing) |
| **jakkra** | 608ZZ + SKF 6005 | PVC | Servo arm direct | Two different bearing types |
| **JPL OSR** | Flanged 8×14×5mm | goRail | Servo through bracket | Different bearing class |
| **Our design** | 1× 608ZZ | 8mm | Horn link 4-bar (EA-27) | Unique linkage, consider dual bearing |

**Note:** Sawppy uses TWO 608ZZ bearings per steering pivot (top + bottom). We use ONE. Consider whether we need dual bearings for robustness.

---

## Parts We Should Adapt From Other Projects

1. **Sawppy DiffBrace** — Add printed brace around our diff bar (it WILL bend)
2. **JPL OSR asymmetric spacers** — Prevent lateral flex on bogie pivot
3. **Sawppy E-clip retention** — Alternative to grub screws (more secure)
4. **jakkra .f3z import** — Visual reference overlay in our Fusion 360 assembly
5. **Sawppy shaft proportions** — Cross-reference our rod lengths

## Parts We Should NOT Adapt

1. Sawppy extrusion clamps (different structural approach)
2. ExoMy triple-bogie (different suspension type)
3. JPL OSR aluminium construction (too expensive)
4. Magnetic bearings (not robust)

---

## Key Sources

- Sawppy GitHub: https://github.com/Roger-random/Sawppy_Rover
- Sawppy Diff Bar Brace: https://newscrewdriver.com/2018/06/01/differential-bar-brace-completes-mechanical-assembly-of-sawppy-rover/
- Sawppy Heat-Set Issues: https://newscrewdriver.com/2020/11/25/sawppy-issue-heat-set-insert-shaft-coupling/
- Sawppy Suspension Geometry: https://newscrewdriver.com/2018/05/24/copying-curiosity-rover-suspension-geometry-for-sawppy-the-rover/
- jakkra Mars-Rover: https://github.com/jakkra/Mars-Rover
- JPL OSR Docs: https://open-source-rover.readthedocs.io/en/latest/mechanical/rocker_bogie/
- HowToMechatronics: https://howtomechatronics.com/projects/diy-mars-perseverance-rover-replica-with-arduino/
- ExoMy: https://github.com/esa-prl/ExoMy
- Fishbone Mini Rover: https://www.printables.com/model/164147
- ROVER-X: https://hackaday.io/project/170953-rover-x
- Rover-One (Fusion 360): https://github.com/chetanborse1999/Rover-One

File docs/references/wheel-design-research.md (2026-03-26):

# Mars Rover Wheel Design Research

**Date:** 2026-03-26
**Purpose:** Find open-source wheel designs to adapt rather than designing from scratch.
**Key decision:** Two-piece hub + interchangeable tire system with Mars rover aesthetics (spiral spokes, chevron grousers).

---

## Our Target Specs

- 80mm diameter, 32mm width (0.4 scale)
- N20 motor with 3mm D-shaft
- 4mm axle bore through knuckle
- Printable on CTC Bizer (225×145×150mm, PLA)
- Two-piece: rigid hub/rim + swappable tire/tread

---

## Top Candidate Designs

### 1. jakkra Mars-Rover 2020 Wheel ★★★ (RECOMMENDED)
- **URL:** https://github.com/jakkra/Mars-Rover (CAD/rover_2020_wheel_flex.f3d)
- **License:** MIT
- **Format:** Fusion 360 .f3d (directly editable!)
- **Design:** Two-piece (PLA hub + TPU outer tire), 6 curved spring-like spokes (Perseverance style)
- **Tread:** Chevron grousers
- **Dimensions:** ~125mm diameter (needs scaling to 80mm)
- **Hub:** Pololu 1081 adapter for JGA25-370 motor (4mm D-shaft) — needs redesign for 3mm N20
- **Adaptation:** MEDIUM — scale down, redesign hub bore for N20, convert outer tire from TPU to PLA+O-rings or beadlock
- **Why best:** Fusion 360 native, MIT license, two-piece, beautiful Perseverance aesthetics

### 2. Sawppy Rover Wheel ★★★
- **URL:** https://github.com/Roger-random/Sawppy_Rover
- **License:** MIT
- **Format:** Onshape + STL
- **Design:** One-piece, 6 curved spokes (Curiosity style), 48 curved grousers
- **Dimensions:** ~120mm diameter
- **Hub:** 8mm bore for steel drive shaft
- **Adaptation:** MEDIUM-HARD — one-piece (no separate tire), Onshape not Fusion 360, 8mm bore vs our 3mm
- **Key value:** Most community-tested rover wheel, excellent FDM-optimised spoke design

### 3. OpenPerseverance (JeanetteMueller) ★★☆
- **URL:** https://github.com/JeanetteMueller/OpenPerseverance
- **License:** CC0 (public domain — no restrictions!)
- **Format:** STL only (no parametric CAD)
- **Design:** FOUR-PIECE: Tire.stl + Wheel Rim.stl + WheelHolder.stl + WheelHolderCenter.stl
- **Tread:** Perseverance-accurate curved grousers (48 treads)
- **Dimensions:** ~150-200mm (needs significant scaling)
- **Adaptation:** HARD — STL only, large scale, different motor

### 4. 120x60mm Two-Piece Rover Wheel ★★☆
- **URL:** Found via STLFinder (original source TBD)
- **Format:** STL
- **Design:** Two-piece (outer wheel + inner hub via slot channels)
- **Hub:** 3mm shaft bore (matches N20 directly!)
- **Dimensions:** 120mm × 60mm
- **Adaptation:** EASY mechanically — already has 3mm bore, but aesthetics are plain (not Mars-like)

### 5. N20-Specific Wheels (Functional Reference)
- **O-Ring Wheels for N20:** https://www.printables.com/model/71090 (small ~25mm)
- **Big Wheels for N20:** https://www.printables.com/model/881194 (68mm, silicone hairbands)
- **Simple N20 Wheels:** https://www.printables.com/model/572952 (PLA hub + TPU tire)

---

## Tire Attachment Mechanisms

| Method | Description | Swap Ease | Strength | Best For |
|---|---|---|---|---|
| **Beadlock ring** | Tire clamped between rim and ring with M2 screws | Easy (4-6 screws) | High | Our recommended approach |
| **Press-fit** | TPU tire stretches over hub | Moderate | Medium | TPU tires (Phase 1C) |
| **Lipped channel** | Tire sits in groove, lips prevent lateral migration | Moderate | Good | Simple single-material |
| **Snap clips** | Integral snap features on rim | Quick | Lower | Rapid testing |
| **O-ring grooves** | Circumferential grooves accept rubber O-rings | Easiest | Low | Hard surface only |
| **Screw-through** | Bolts through rim and tire bead | Slow | Highest | Competition rovers |

**Recommended for us:** Simplified beadlock (4× M2 screws) — easy to swap, secure, works with PLA or TPU tires.

---

## Interchangeable Tire Tread Patterns

| Pattern | Terrain | Description |
|---|---|---|
| **Mars Chevron** | Garden soil, gravel, loose substrate | Angled V-pattern grousers (Curiosity/Perseverance style) |
| **Deep Lugs** | Mud, wet grass | Widely-spaced tall blocks, self-cleaning gaps |
| **Paddle** | Sand, snow, loose substrate | Full-width perpendicular scoops |
| **Smooth/Slick** | Indoor, hard floor, pavement | No tread, maximum contact patch |
| **All-Terrain Hybrid** | Mixed conditions | Combination chevrons + lateral channels |
| **Hex Lattice** | All-terrain (TPU only) | Honeycomb structure acts as suspension + tread |

---

## Parametric Wheel Generators

| Project | URL | License | Notes |
|---|-----|---|---|
| Highly Configurable Wheel | https://github.com/alexfranke/Highly-Configurable-Wheel | Permissive | OpenSCAD, 46 params, 13 tread patterns |
| OpenScadWheelGenerator | https://github.com/UladzimirKapylou/OpenScadWheelGenerator | MIT | Two-piece hub+tire generation |
| openWheel | https://github.com/sarinkhan/openWheel | GPL-3.0 | Wheels, tweels, tires, tracks |

---

## TPU on CTC Bizer — Feasibility

The CTC Bizer has direct-drive MK8 extruders which CAN handle TPU with modification:
- **Required:** Filament guide insert (Printables #18671 or Thingiverse #1524455)
- **Settings:** 225-230°C, 40-60°C bed, 20-40mm/s speed, 1-2mm retraction
- **Material:** Shore 95A recommended (easier than softer grades)
- **Priority:** Get PLA working first, then try TPU after calibration

---

## Recommended Approach

1. **Import jakkra `rover_2020_wheel_flex.f3d`** into Fusion 360 as reference
2. **Adapt the hub:** Scale to 80mm, redesign bore for 3mm N20 D-shaft, keep spiral spoke aesthetic
3. **Redesign retention:** Add beadlock-style rim groove with M2 screw retention ring
4. **Create tire set:** 3-4 interchangeable PLA tread bands (Mars chevron, lugs, paddle, smooth)
5. **Phase 1C:** Try TPU tires once CTC Bizer is calibrated with PLA

---

## Key Sources

- jakkra Mars-Rover: https://github.com/jakkra/Mars-Rover
- Sawppy Rover: https://github.com/Roger-random/Sawppy_Rover
- Sawppy Wheel Blog: https://newscrewdriver.com/2018/05/10/sawppy-feet-1-0-rover-wheel-design-for-3d-printing/
- OpenPerseverance: https://github.com/JeanetteMueller/OpenPerseverance
- Highly Configurable Wheel: https://github.com/alexfranke/Highly-Configurable-Wheel
- CTC Bizer TPU Guide: https://www.thingiverse.com/thing:1524455
- Beadlock Reference: https://www.thingiverse.com/thing:2950547
- Palmiga OpenRC Wheels: https://www.thingiverse.com/thing:526969
- NASA Perseverance Wheels: https://mars.nasa.gov/mars2020/spacecraft/rover/wheels/

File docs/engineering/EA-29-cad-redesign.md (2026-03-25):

# EA-29: CAD Redesign — Print-Ready Phase 1 Parts

**Date:** 2026-03-25
**Author:** Claude Opus 4.6 + Charlie
**Status:** Complete
**Supersedes:** Original placeholder scripts (pre-redesign)
**References:** EA-08, EA-11, EA-25, EA-26, EA-27, EA-28

---

## 1. Background

All 22 CAD scripts originally produced basic placeholder geometry (rectangular blocks with simple holes). None were print-ready. A complete redesign was undertaken to produce proper, printable, engineered parts with:

- Rounded-rect bodies (2mm corner radius) on all external outlines
- 0.5mm fillets on all external edges (PLA layer adhesion, stress relief)
- 0.3mm chamfers on all insertion features (bearing seats, tube sockets, motor pockets)
- Shared helper module to guarantee dimensional consistency
- Proper mating features (heat-set inserts, through-holes, grub screws)

## 2. Architecture

### 2.1 Shared Helper Module: `rover_cad_helpers.py`

Central module imported by all 22 scripts. Eliminates code duplication and ensures every hardware interface is dimensionally identical across all parts.

**Constants (cm, Fusion 360 API units):**

| Constant | Value (cm) | Value (mm) | Purpose |
|---|---|---|---|
| FILLET_STD | 0.05 | 0.5 | External edge fillets |
| CHAMFER_STD | 0.03 | 0.3 | Insertion chamfers |
| CORNER_R | 0.2 | 2.0 | Rounded-rect corner radius |
| BEARING_OD | 2.215 | 22.15 | 608ZZ bore (0.15mm oversize) |
| BEARING_DEPTH | 0.72 | 7.2 | 608ZZ seat depth (0.2mm extra) |
| BEARING_BORE | 0.81 | 8.1 | 608ZZ shaft bore (0.1mm clearance) |
| TUBE_BORE | 0.82 | 8.2 | 8mm rod socket bore |
| TUBE_DEPTH | 1.5 | 15.0 | Rod engagement depth |
| TUBE_WALL | 0.4 | 4.0 | Minimum wall around tube socket |
| GRUB_M3 | 0.15 | 1.5 | M3 grub screw bore radius |
| INSERT_BORE | 0.24 | 2.4 | M3 heat-set insert bore radius |
| INSERT_DEPTH | 0.55 | 5.5 | Heat-set insert pocket depth |
| N20_W | 1.22 | 12.2 | N20 motor clip width |
| N20_H | 1.02 | 10.2 | N20 motor clip height |
| N20_D | 2.5 | 25.0 | N20 motor clip depth |
| SG90_W | 2.24 | 22.4 | SG90 servo pocket width |
| SG90_D | 1.22 | 12.2 | SG90 servo pocket depth |

**Helper Functions:**

| Function | Creates | Used By |
|---|---|---|
| `draw_rounded_rect()` | Rectangle with filleted corners | 18 scripts |
| `draw_stadium()` | Capsule/stadium shape | steering_knuckle |
| `find_profile_by_area()` | Robust profile selection | All scripts |
| `find_largest_profile()` | Largest sketch profile | Fallback |
| `find_smallest_profile()` | Smallest sketch profile | Bores, holes |
| `extrude_profile()` | New body extrusion | Body creation |
| `cut_profile()` | Cut extrusion | Pockets, bores |
| `join_profile()` | Join extrusion | Gussets, ribs |
| `make_offset_plane()` | Construction plane | Feature placement |
| `make_bearing_seat()` | 608ZZ bore + chamfer + shaft | 4 scripts |
| `make_n20_clip()` | N20 motor pocket + snap tab | 2 scripts |
| `make_sg90_pocket()` | SG90 servo pocket + tab slots | 1 script |
| `make_heat_set_pair()` | 2× M3 insert pockets | 6 scripts |
| `make_m3_grub_hole()` | M3 grub screw bore | 4 scripts |
| `add_edge_fillets()` | All external edge fillets | All scripts |
| `add_chamfer()` | Circular bore entry chamfer | 5 scripts |
| `add_triangular_gusset()` | Reinforcement gusset | 4 scripts |

### 2.2 Assembly Pattern

A critical design decision governs how parts bolt together:

- **Connectors** (structural base parts that stay on the suspension tubes): receive **M3 heat-set inserts** (4.8mm bore, 5.5mm depth)
- **Brackets/mounts** (removable parts that bolt TO connectors): receive **M3 clearance through-holes** (3.3mm diameter)

This ensures a bolt passes through the bracket and threads into the connector's insert. Two insert faces cannot be bolted together.

| Part | Role | Fastener Type |
|---|---|---|
| front_wheel_connector | Connector | Heat-set inserts |
| middle_wheel_connector | Connector | Heat-set inserts |
| steering_bracket | Bracket (bolts to connector) | M3 through-holes |
| servo_mount | Bracket (bolts to connector) | M3 through-holes |
| fixed_wheel_mount | Bracket (bolts to connector) | M3 through-holes |
| body_quadrant | Base structure | Heat-set inserts |
| top_deck | Cover (clips to body) | Snap clips |

### 2.3 Script Count

| Category | Scripts | STLs |
|---|---|---|
| Calibration | 3 | 3 |
| Wheels | 2 | 2 |
| Steering | 5 | 5 |
| Suspension | 6 | 6 |
| Body | 3 | 11 (4 quadrants + 4 tiles + tray + 2) |
| Accessories | 4 | 4 |
| **Total** | **23 scripts** | **29 STLs** |

Plus: `rover_cad_helpers.py` (shared module), `rover_assembly_v2.py` (visual assembly), `batch_export_all.py` (STL export automation).

## 3. Design Decisions

### 3.1 Why Rounded-Rect Bodies?

Plain rectangular blocks have sharp edges that:
- Catch on things during handling
- Create stress concentration points
- Look cheap and unfinished
- Risk layer delamination at sharp PLA corners

2mm corner radius was chosen as the minimum that provides a visible improvement while remaining printable at 0.4mm nozzle width (5 perimeters at 0.4mm = 2.0mm).

### 3.2 Why 0.5mm Fillets?

The standard fillet radius (0.5mm) was chosen because:
- Single layer height (0.2mm × 2.5 = 0.5mm) — prints as gradual steps
- Eliminates stress risers at edge intersections
- Applied via `add_edge_fillets()` which iterates all body edges with try/except per edge (some edges can't be filleted due to geometry conflicts)

### 3.3 Why Shared Helpers?

Without shared helpers, the bearing seat code would be duplicated in 4 scripts, tube socket code in 6 scripts, etc. Any tolerance adjustment would require editing N files. The helper module ensures:
- **Single source of truth** for all hardware dimensions
- **Consistent fitment** across all parts
- **Easy tolerance adjustment** — change one constant, all parts update

### 3.4 Clearance Strategy

All press-fit and sliding-fit dimensions include PLA-specific clearances:

| Interface | Nominal | Actual | Clearance | Reason |
|---|---|---|---|---|
| 608ZZ seat | 22.0mm | 22.15mm | +0.15mm | PLA shrinkage, press fit by hand |
| 608ZZ shaft | 8.0mm | 8.1mm | +0.1mm | Shaft must slide through |
| Tube socket | 8.0mm | 8.2mm | +0.2mm | Rod slides in, grub screw retains |
| N20 clip | 12.0×10.0mm | 12.2×10.2mm | +0.2mm | Snap fit with retention tab |
| SG90 pocket | 22.2×11.8mm | 22.4×12.2mm | +0.2/+0.4mm | Drop in from top |
| Heat-set bore | 5.7mm | 4.8mm | -0.9mm | Undersized for heat press-in |

### 3.5 Print Orientation

Every part has a documented print orientation chosen for:
1. No supports needed (all overhangs <45°)
2. Maximum strength in the load direction
3. Best surface finish on visible/mating faces

## 4. Errors Encountered and Fixes

### 4.1 CRITICAL: `draw_rounded_rect` Arc Direction Bug

**Error:** The top-left corner arc in `draw_rounded_rect()` swept counterclockwise (+π/2) instead of clockwise (-π/2). This created an open curve instead of a closed profile.

**Impact:** Every script that used `draw_rounded_rect()` (18 of 22) produced 0 profiles, 0 bodies, and 0 STL output. BatchExportAll reported 12/29 STLs (only scripts using plain rectangles, revolves, or fallback geometry worked).

**Root Cause:** The three other corners correctly used `-half_pi` (clockwise). The top-left corner was the only one using `+half_pi` — a copy-paste error during helper module creation.

**Fix:** Changed line 200 of `rover_cad_helpers.py`:
```python
# Before (BROKEN):
arcs.addByCenterStartSweep(p(*tl), p(cx - hw, tl[1]), half_pi)
# After (FIXED):
arcs.addByCenterStartSweep(p(*tl), p(cx - hw, tl[1]), -half_pi)
```

**Lesson:** Always test helper functions with a simple extrude immediately after creation. A single profile count check (`assert sk.profiles.count > 0`) would have caught this before 18 scripts were affected.

### 4.2 CRITICAL: `draw_rounded_rect` Missing Arguments in Phase 6 Scripts

**Error:** 4 Phase 6 scripts (strain_relief_clip, fuse_holder_bracket, switch_mount, battery_tray) called `draw_rounded_rect(sk, W, H, R)` with only 4 arguments instead of `draw_rounded_rect(sk, 0, 0, W, H, r=R)` with 5 positional + keyword.

**Impact:** Would cause `TypeError` at runtime.

**Root Cause:** Phase 6 scripts were written without checking the function signature.

**Fix:** Added `0, 0,` for cx/cy and `r=` keyword for radius in all 7 affected calls.

**Lesson:** Always import and call helpers in a test before using in production scripts.

### 4.3 IMPORTANT: Bolt Spacing Mismatch

**Error:** `fixed_wheel_mount.py` had `BOLT_SPACING = 1.5` (15mm) while `middle_wheel_connector.py` had `MOUNT_BOLT_SPACING = 1.6` (16mm). These parts bolt together.

**Impact:** 1mm bolt hole misalignment — parts wouldn't assemble.

**Fix:** Changed `fixed_wheel_mount.py` to `BOLT_SPACING = 1.6`.

**Lesson:** Cross-reference ALL mating interfaces during audit. Create a mating interface matrix.

### 4.4 IMPORTANT: Diff Bore Zero Clearance

**Error:** `rocker_hub_connector.py` had `DIFF_BORE_R = 0.4` (8.0mm bore) for an 8mm rod — zero clearance.

**Impact:** Part would not assemble with PLA shrinkage.

**Fix:** Changed to `DIFF_BORE_R = 0.41` (8.2mm bore, matching TUBE_BORE constant).

**Lesson:** All sliding-fit bores should reference shared constants (TUBE_BORE, BEARING_BORE) rather than hardcoding values.

### 4.5 IMPORTANT: Heat-Set Inserts on Both Mating Faces

**Error:** `steering_bracket.py`, `servo_mount.py`, and `fixed_wheel_mount.py` all had heat-set insert pockets for their mounting holes — but they bolt TO connectors that also have inserts.

**Impact:** Cannot bolt two insert faces together (no bolt path).

**Fix:** Replaced `make_heat_set_pair()` calls with M3 clearance through-holes (3.3mm diameter) in all 3 bracket scripts.

**Lesson:** Establish the assembly pattern (connectors=inserts, brackets=through-holes) early and document it prominently.

### 4.6 MINOR: Assembly Script API Error

**Error:** `rover_assembly_v2.py` used `importManager.createSTLImportOptions()` which doesn't exist in Fusion 360 API.

**Impact:** Assembly script failed on first run.

**Fix:** Replaced with `meshBodies.add()` API and switched design to direct mode.

**Lesson:** Always verify API methods exist before coding against them. The Fusion 360 API docs don't include STL import via ImportManager.

### 4.7 IMPORTANT: Assembly STL Import Unit Bug

**Error:** `rover_assembly_v2.py` used `MeshUnits.CentimeterMeshUnit` to import STL files, but Fusion 360 exports STLs in millimeters. This caused all 53 imported parts to be 10x too large.

**Impact:** Assembly visualization was completely wrong — body panels dominated the view at 1300mm x 2200mm instead of 130mm x 220mm.

**Root Cause:** Assumed Fusion 360 STL export used the API's internal centimeter units, but STL export always writes in millimeters (the 3D printing standard).

**Fix:** Changed to `MeshUnits.MillimeterMeshUnit` on line 323 of `rover_assembly_v2.py`.

**Verification:** STL info confirmed `bearing_test_piece.stl` dimensions are 32.8 x 32.8 x 12mm (matching the 32mm x 32mm x 12mm design spec).

**Lesson:** Always verify import/export units match by checking a known-dimension part's STL bounding box before importing.

## 5. Verification

### 5.1 Individual Script Testing

All 22 part scripts + 1 battery tray (new) were tested via MCP execute_code:

```
OK: BearingTestPiece — 1 bodies
OK: ServoMount — 1 bodies
OK: RockerHubConnector — 1 bodies
OK: FrontWheelConnector — 1 bodies
OK: MiddleWheelConnector — 1 bodies
OK: SwitchMountPlate — 1 bodies
OK: BatteryTray — 1 bodies
OK: SteeringKnuckle — 2 bodies (main + arm extension)
OK: DifferentialPivotHousing — 3 bodies (main + flanges)
OK: BodyQuadrant — 7 bodies (main + ribs/panels)
OK: TopDeck — 1 bodies
OK: ElectronicsTray — 1 bodies
OK: SteeringBracket — 1 bodies
OK: FixedWheelMount — 3 bodies (main + gussets)
OK: StrainReliefClip — 1 bodies
OK: FuseHolderBracket — 1 bodies
OK: CableClip — 2 bodies (main + arm)
```

### 5.2 Batch Export

```
Components processed: 29/29
STL files exported:   29
Errors:               0
Elapsed time:         182s (3.0 min)
Total STL size:       ~35 MB
```

### 5.3 STL File Sizes (Sanity Check)

All STL files have reasonable sizes indicating proper geometry:
- Smallest: rover_tire.stl (99 KB) — simple revolve
- Largest: body_quadrant_fl.stl (3944 KB) — complex panel with ribs
- Average: ~600 KB per part

No 0 KB or suspiciously small files.

## 6. Files Created/Modified

### New Files
| File | Purpose |
|---|---|
| `cad/scripts/rover_cad_helpers.py` | Shared helper module (~500 lines) |
| `cad/scripts/battery_tray.py` | 2S LiPo cradle (new part) |
| `cad/scripts/rover_assembly_v2.py` | Full assembly visualisation |
| `3d-print/body/battery_tray.stl` | Battery tray STL export |

### Modified Files (22 redesigned scripts)
All scripts in `cad/scripts/` except deprecated, superseded, and utility scripts.

### Git Tag
`v1.0.0-cad-redesign` — complete checkpoint before further modifications.

## 7. Open Items

1. **Assembly positioning** — rover_assembly_v2.py uses approximate positions; exact kinematic positioning would require solving the suspension geometry
2. **Multi-body cleanup** — Some scripts create extra bodies (gussets, ribs) that don't join to the main body; cosmetic issue, doesn't affect STL export
3. **Tolerance validation** — All clearances are theoretical; actual PLA fitment requires test prints (bearing test piece, tube socket test)
4. **CTC Bizer calibration** — Printer hasn't been used in years; calibration prints needed before production parts

## 8. Recommendations

1. Print calibration pieces FIRST: bearing_test_piece, tube_socket_test, calibration_test_card
2. Validate fitment before committing to full part prints
3. If bearing seat is too tight, increase `BEARING_OD` in `rover_cad_helpers.py` by 0.05mm increments
4. If tube socket is too loose, decrease `TUBE_BORE` by 0.05mm increments
5. All changes propagate automatically through shared helpers to all scripts

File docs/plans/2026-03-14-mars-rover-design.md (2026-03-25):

# Mars Rover Garden Robot — Complete Design Document

**Project**: Charlie's Mars Rover
**Date**: 2026-03-14 (updated 2026-03-15)
**Version**: 1.3
**Status**: Design Phase — Engineering Analysis Complete, Phase 1 Firmware Started
**Engineering References**: EA-00 through EA-30 in `docs/engineering/`
**Research References**: `docs/references/` (3D printing materials, ROS2 architecture)

---

## Table of Contents

1. [Project Overview](#1-project-overview)
2. [System Architecture](#2-system-architecture)
3. [Chassis & Suspension](#3-chassis--suspension)
4. [Power System](#4-power-system)
5. [Compute & Networking](#5-compute--networking)
6. [Vision & Sensors](#6-vision--sensors)
7. [Robotic Arms & Mast](#7-robotic-arms--mast)
8. [Software Architecture](#8-software-architecture)
9. [Accessories](#9-accessories)
10. [Bill of Materials](#10-bill-of-materials)
11. [Build Phases](#11-build-phases)
12. [Risk Register](#12-risk-register)

---

## 1. Project Overview

### Purpose
A Mars rover-inspired outdoor robot that serves as a functional vehicle, AI-powered exploration platform, utility robot, learning project, and coffee table when parked.

### Key Parameters

| Parameter | Value |
|---|---|
| Size (LxWxH driving) | 1100mm x 650mm x 1050mm |
| Size (coffee table) | 1100mm x 650mm x 450mm |
| Weight (Phase 2, 3D printed) | ~16.7 kg (EA-05) |
| Weight (Phase 3, metal) | ~20.8 kg (EA-05) |
| Budget | $2,031.75 total (EA-06) |
| Top speed target | 5 km/h (132.8 wheel RPM) (EA-02) |
| Runtime (driving, all systems) | ~4.0 hours (EA-03) |
| Runtime (driving, no fridge) | ~6.4 hours (EA-03) |
| Runtime (stationary) | ~12+ hours (EA-03) |
| Typical power draw | 97.5W (5.17A at battery) (EA-03) |
| Terrain | All surfaces — grass, gravel, slopes, pavement |
| Max slope | 30° (33.5 kg·cm torque/wheel worst case) (EA-02) |
| Control modes | Manual, autonomous, hybrid |
| Compute | Jetson Orin Nano Super ($249) + ESP32-S3 (EA-04) |
| CAD | Fusion 360 |
| 3D Printer | CTC 3D Bizer (225x145x150mm) |

### Build Phases

| Phase | Scale | Material | Goal |
|---|---|---|---|
| 1 | 0.4x (~45x28cm) | PLA | Test rocker-bogie, basic driving |
| 2 | 1.0x (110x65cm) | PETG/ASA + aluminium extrusion | Full electronics, all features |
| 3 | 1.0x (110x65cm) | Aluminium/steel machined + 3D printed housings | Production quality, weatherproof |

---

## 2. System Architecture

### Subsystems (8 total)

| # | Subsystem | Description |
|---|---|---|
| 1 | Chassis & Suspension | Rocker-bogie linkage, body frame, coffee table conversion |
| 2 | Drivetrain | 6× Chihai 37mm 80RPM DC gearmotors + 4× MG996R steering servos (EA-02) |
| 3 | Power | 2× 6S 10Ah LiPo (444Wh), 100W solar, BMS, buck converters (EA-03) |
| 4 | Compute & Networking | Jetson Orin Nano Super (67 TOPS) + ESP32-S3 + PCA9685 PWM driver (EA-04) |
| 5 | Vision & Sensors | 4× Arducam 120° + ELP 10× zoom + OAK-D Lite + Pi NoIR + RPLidar A1 (EA-04) |
| 6 | Robotic Arms & Mast | Folding camera mast, articulated arms with grippers |
| 7 | Software | ROS2, AI vision, navigation, phone PWA, firmware |
| 8 | Accessories | Mini fridge, phone charging, LEDs, weather station, speaker, display |

### Dual-Controller Architecture

```
[Jetson Orin Nano Super]              [ESP32-S3]
  - AI vision (67 TOPS)               - Motor PWM control (6×)
  - Path planning (Nav2)              - Sensor polling (6× ultrasonic)
  - Camera streams (7×)               - Wheel encoder reading (6×)
  - GPS navigation                     - Battery monitoring (ADC)
  - Phone app server                   - IMU polling (BNO055, I2C)
  - ROS2 Isaac nodes                  - Watchdog / safety
  - Voice commands                     - LED control (WS2812B)
  - LIDAR SLAM                        - Weather station sensors
        |                                    |
        +------------- UART 115200 ---------+
                                             |
                                      [PCA9685 I2C]
                                        - 14× servo PWM
                                        (4 steering + 8 arm + 2 mast)
```

The Jetson handles all "smart" processing. The ESP32-S3 handles real-time motor/sensor control via PCA9685 I2C PWM driver (solves GPIO pin shortage — 50 pins needed, 36 available, EA-04). If the Jetson crashes, the ESP32 safely stops all motors (watchdog pattern, proven on Clock/Lamp projects).

---

## 3. Chassis & Suspension

### Rocker-Bogie Geometry

NASA's rocker-bogie suspension uses no springs and no axles — pure geometry keeps all 6 wheels on the ground over uneven terrain.

```
Side View:
                    [Differential Bar]
                         /    \
                        /      \
            [Rocker L]            [Rocker R]
           /          \          /          \
         W1    [Bogie L]      [Bogie R]    W6
              /       \      /       \
            W2        W3   W4        W5

Top View (1100mm x 650mm):
    +-------------------------------------+
    |  W1(s)                      W6(s)   |   s = steered
    |    |                          |     |
    |    +--[Rocker]--+  +--[Rocker]--+   |
    |    |            |  |            |   |
    |  W2             +--+           W5   |
    |    |            |  |            |   |
    |    +--[Bogie]---+  +--[Bogie]---+   |
    |    |                          |     |
    |  W3(s)                      W4(s)   |   s = steered
    +-------------------------------------+
```

### Dimensions

| Parameter | Value | Reasoning / Source |
|---|---|---|
| Overall length | 1100mm | Coffee table proportions |
| Overall width | 650mm | Fits through standard doorways |
| Track width (wheel-to-wheel) | 700mm | NASA ratio 0.82× wheelbase, adjusted for body (EA-01) |
| Wheelbase (W1-W3) | 900mm | Front to rear wheel per side (EA-01) |
| Rocker arm length | 450mm | NASA ratio 0.50× wheelbase (EA-01) |
| Bogie arm length | 300mm (150+150) | NASA ratio 0.32× wheelbase, 1.50:1 rocker:bogie (EA-01) |
| Ground clearance | 150mm | Adequate for park terrain, kerbs |
| Wheel diameter | 200mm | Max obstacle climb ~150mm practical (EA-01) |
| Wheel width | 80mm | Good traction, not too heavy |
| Body height (wheels to deck) | 300mm | Room for electronics bay |
| Mast height (extended) | 600mm above deck | Good camera vantage |
| Total height (mast up) | ~1050mm | Practical standing height |
| Total height (mast down) | ~450mm | Standard coffee table height |
| Weight (Phase 2) | 16.7 kg | Component-by-component estimate (EA-05) |
| Weight (Phase 3) | 20.8 kg | +4.1 kg for metal panels/hubs (EA-05) |
| Centre of gravity | 232mm above ground | Calculated from component positions (EA-05) |
| Max tilt angle (before tip) | 49° (conservative) | With elevated CoG estimate (EA-01) |
| Bearings | 9× 608ZZ (8mm bore, buy 12) | All pivot points + wheel axles (EA-01) |

### Wheel Design

Each wheel features:
- Cleats/grousers on the tread (Mars rover aesthetic)
- Flexible spoke design (not solid disc) for compliance over bumps
- Hub motor mount — each wheel has its own DC gearmotor
- Corner steering — W1, W3, W4, W6 have servo-driven steering; W2, W5 are fixed

### Steering Modes

| Mode | Description | Use Case |
|---|---|---|
| Normal (Ackermann) | 4 corner wheels turn proportionally | Regular driving |
| Point turn | All 4 steered wheels turn opposite | Spin on the spot, tight spaces |
| Crab walk | All 4 steered wheels turn same direction | Lateral/sideways movement |

### Coffee Table Conversion

- Mast folds flat with a locking hinge
- Solar panels fold in and lay flat
- Optional clear acrylic/glass top panel clicks on for smooth surface
- Wheels lock straight, parking brake engages (motor brake)
- LEDs switch to ambient warm glow underglow
- Wheels remain at sides in normal position (no retraction needed)

### Body Frame Structure

Modular tray system designed for CTC Bizer (225x145mm bed):

```
Top deck:  [Panel A1][Panel A2][Panel A3][Panel A4][Panel A5]
           Each ~220x130mm, bolted with alignment pins + M4 bolts

Frame:     2020 aluminium extrusion rails as skeleton
           Gives rigidity that 3D printed panels alone can't provide

Bottom:    Sealed electronics bay with cable pass-throughs
           IP54 rated gaskets for weather resistance (Phase 3)
```

Phase 2 uses aluminium extrusion skeleton + printed panels bolted on.
Phase 3 replaces printed panels with sheet aluminium/steel.

---

## 4. Power System

### Power Budget (EA-03)

| Consumer | Voltage | Peak (A) | Typical (A) | Typical (W) |
|---|---|---|---|---|
| 6× Drive motors (Chihai 37mm) | 12V | 24.0 | 1.2 | 14.4 |
| 4× Steering servos (MG996R) | 6V | 8.0 | 0.2 | 1.2 |
| Jetson Orin Nano Super | 5V | 3.0 | 2.0 | 10.0 |
| ESP32-S3 | 3.3V | 0.5 | 0.15 | 0.5 |
| 6× Cameras | 5V | 3.0 | 1.5 | 7.5 |
| RPLidar A1 | 5V | 1.0 | 0.7 | 3.5 |
| OAK-D Lite depth | 5V | 1.0 | 0.8 | 4.0 |
| Mini fridge (Peltier) | 12V | 5.0 | 3.0 | 36.0 |
| LED underglow + lights | 5V | 3.0 | 1.0 | 5.0 |
| Speaker/amp | 12V | 2.0 | 0.3 | 3.6 |
| Qi charger | 5V | 2.0 | 1.0 | 5.0 |
| Dashboard display | 5V | 0.3 | 0.2 | 1.0 |
| GPS + IMU + sensors | 3.3V | 0.2 | 0.1 | 0.3 |
| 8× Arm servos + 2× Mast servos | 6V | 20.0 | 1.3 | 7.8 |
| Weather station | 3.3V | 0.1 | 0.05 | 0.2 |
| 4G modem | 5V | 0.5 | 0.3 | 1.5 |
| **Total at battery** | | **~50A peak** | **~13A typical** | **97.5W** |

Battery current (typical): 97.5W / (22.2V × 0.85 efficiency) = **5.17A**

### Battery Design (EA-03)

```
Main Battery Pack: 6S LiPo (22.2V nominal, 25.2V full)
Capacity: 20Ah (444Wh)
Config: 2× Turnigy 6S 10000mAh 12C in parallel (swappable)
Weight: ~1.7 kg total (850g each)
Dimensions: ~185×70×58mm per pack
Peak current: 15.9A (trivial for 12C packs — can deliver 120A each)

[Battery Pack A: 6S 10Ah]  [Battery Pack B: 6S 10Ah]
         |                           |
     [BMS A: 6S 30A]          [BMS B: 6S 30A]
         |                           |
         +------ Parallel -----------+
                    |
            [E-Stop + Main Relay (30A)]
                    |
            [Power Distribution Board]
                    |
    +---------------+---------------+---------------+
    |               |               |               |
[Buck 22V→12V]  [UBEC 22V→6V]  [Buck 22V→5V]  [LDO 5V→3.3V]
XL4016 10A      Hobbywing 5A    XL4015 8A      AMS1117
90% eff         85% eff         88% eff         66% eff
Motors,         Steering+Arm    Jetson,         Weather
Fridge,         Servos          Cameras,        sensors
Speaker                         LEDs, Qi,
                                Display
```

### Estimated Runtime (EA-03 — calculated with converter efficiencies)

| Mode | Power Draw | Runtime (444Wh) |
|---|---|---|
| Driving + all systems (incl. fridge) | 97.5W | ~4.0 hours |
| Driving without fridge | 61.5W | ~6.4 hours |
| Stationary (coffee table, fridge on) | ~50W | ~8 hours |
| Idle (sensors + compute only) | ~25W | ~16 hours |

### Solar Panel Array

```
Folded (coffee table):        Deployed:
  +----------+               /Panel 1\
  | Panels   |              /---------\
  | stacked  |    -->      |  Top Deck  |
  | on deck  |              \---------/
  +----------+               \Panel 2/
```

- 4× 25W monocrystalline panels = 100W total
- Wired 2S2P (~36V open circuit) — higher than battery voltage for buck MPPT (EA-03)
- CN3722 solar MPPT charge controller (~$15) (EA-06)
- Spring-loaded stainless hinges with locking detents
- Full charge from solar: ~10hrs (summer UK) to ~26hrs (winter UK) (EA-03)
- Realistic solar contribution: extends runtime by 1-3 hours depending on season

### Charging Methods

| Method | Details |
|---|---|
| Solar | 100W panels (2S2P), CN3722 MPPT, ~10-26hr full charge (UK) (EA-03) |
| Mains | Barrel jack, 24V 5A charger, ~4hr full charge |
| Docking station | Spring-loaded copper contacts, autonomous dock |

### Safety Features

- BMS per pack: over-charge, over-discharge, over-current, temperature protection
- E-stop: physical red button on body AND software kill from phone
- Low battery auto-return: alert at 20%, autonomous return-to-home at 10%
- Fuse per rail: individual fuses on 12V, 6V, 5V rails
- Battery temperature monitoring: shutdown if packs exceed 60C

---

## 5. Compute & Vision & Sensors (EA-04)

### Camera Array

| Camera | Type | Location | Purpose | Ref |
|---|---|---|---|-----|
| Front main | Arducam B0205 120° USB ($15) | Front body, below deck | Primary driving view, AI object detection | EA-04 |
| Rear | Arducam B0205 120° USB ($15) | Rear body | Reversing camera, rear obstacle detection | EA-04 |
| Left | Arducam B0205 120° USB ($15) | Left body panel | 360 coverage | EA-04 |
| Right | Arducam B0205 120° USB ($15) | Right body panel | 360 coverage | EA-04 |
| Mast cam | ELP 10× optical zoom USB ($50) | Top of mast, pan-tilt mount | Long-range observation, zoom | EA-04 |
| Depth camera | OAK-D Lite ($89) | Front body, next to main cam | Stereo depth, on-device AI, 86° FOV | EA-04 |
| Night vision | Pi NoIR Camera v3 CSI ($25) + 4× IR 850nm LEDs ($5) | Mast | Low-light / night operation | EA-04 |

### 360-Degree View System

```
        [Mast Cam - Zoom + Pan/Tilt]
                   |
    [Left]----[Front]----[Right]
                   |
               [Rear]

Software stitches 4 body cams into panoramic view.
Phone app: swipe to rotate through 360 degrees.
Mast cam is independent — zoom/pan controlled separately.
```

### Sensor Suite

| Sensor | Quantity | Location | Purpose |
|---|---|---|---|
| RPLidar A1 ($73) | 1 | Front body, ~20cm height | 2D/360° SLAM, 12m range, 8000 samples/s (EA-04) |
| BN-220 GPS (u-blox M8) ($12) | 1 | Top deck (clear sky view) | Position tracking, waypoints, geofencing (EA-04) |
| BNO055 IMU ($15) | 1 | Centre of body | 9-DOF orientation, on-chip fusion, tilt detection (EA-04) |
| Ultrasonic (HC-SR04) | 6 | 2 front, 2 side, 2 rear | Close-range obstacle detection (< 4m) |
| Wheel encoders | 6 | Each wheel hub | Odometry, speed measurement |
| Current sensors (INA219) | 4 | Each power rail | Power monitoring, consumption tracking |
| Temperature (DS18B20) | 3 | Battery bay, electronics bay, ambient | Thermal monitoring |
| Voltage divider | 1 | Battery main | Battery voltage monitoring (ESP32 ADC) |

### AI Vision Pipeline (Jetson)

```
Camera Feeds (6x)
      |
[CSI/USB Capture] --> [Pre-process: resize, normalize]
      |
[YOLO v8 / MobileNet] --> Object Detection
      |                     - People
      |                     - Animals
      |                     - Obstacles
      |                     - Vehicles
      |                     - Signs/text
      |
[Depth Fusion] --> Combine RGB detection with depth map
      |
[ROS2 costmap] --> Navigation layer
      |
[Path Planner] --> Avoid obstacles, plan route
```

### LIDAR SLAM (Simultaneous Localization and Mapping)

```
LIDAR Scan (360° @ 8000 samples/sec)
      |
[Hector SLAM / Cartographer] --> 2D occupancy grid map
      |
[Map Server] --> Stores map of environment
      |
[AMCL Localization] --> "Where am I on this map?"
      |
[Navigation Stack] --> Plan path through known map
```

The rover builds a map as it drives. Next time it visits the same location, it knows where it is and can navigate autonomously using the saved map. At Markeaton Park, after one manual drive-through, it could navigate the paths autonomously.

### Sensor Fusion

```
GPS --------+
IMU --------+---> [Extended Kalman Filter] ---> Fused Position/Orientation
Wheel Enc --+           |
LIDAR ------+     [Confidence Score]
                        |
                  High confidence: use for autonomous nav
                  Low confidence: alert user, slow down
```

Multiple sensor inputs are fused using an EKF (Extended Kalman Filter) to produce a single, accurate position estimate. GPS alone is ~3m accuracy; fused with IMU + wheel encoders + LIDAR, this drops to ~10cm.

---

## 6. Robotic Arms & Mast

### Camera Mast

```
Extended:                    Folded (coffee table):
    [Pan-Tilt Head]              _____________
         |                      |  Mast laid  |
    [Extension Tube]            |  flat on    |
    600mm telescoping           |  top deck   |
         |                      |_____________|
    [Hinge Joint]
         |
    [Body Mount]
```

| Parameter | Value |
|---|---|
| Height above deck (extended) | 600mm |
| Rotation range (pan) | 360 degrees continuous |
| Tilt range | -30 to +90 degrees |
| Pan motor | MG996R servo or NEMA 17 stepper |
| Tilt motor | MG996R servo |
| Fold mechanism | Spring-loaded hinge with solenoid lock |
| Cameras on mast | 30x zoom cam, IR night vision cam |

### Pan-Tilt Head Design

```
Top View:                    Side View:
    +-------+                [Tilt Servo]---[Camera Mount]
    | Zoom  |                     |              |
    | Cam   |                [Pan Servo]    [Zoom Cam]
    +-------+                     |         [IR Cam]
    | IR    |                [Bearing]
    | Cam   |                     |
    +-------+                [Mast Tube]

Pan: slip ring for continuous 360 rotation (no cable wrap)
Tilt: standard servo arm, -30 to +90 degrees
```

### Robotic Arms (x2)

Two articulated arms, one on each side of the body:

```
Arm Layout (each arm):

[Shoulder Joint]---[Upper Arm]---[Elbow Joint]---[Forearm]---[Wrist]---[Gripper]
     |                180mm           |             150mm       |         |
  [Servo 1]                      [Servo 2]                 [Servo 3] [Servo 4]
  Rotation                       Bend                      Rotation  Open/Close

Degrees of Freedom: 4 per arm (shoulder rotate, elbow bend, wrist rotate, gripper)
```

| Parameter | Value |
|---|---|
| Reach per arm | ~350mm from shoulder |
| Payload per arm | ~500g (Phase 2 3D print), ~2kg (Phase 3 metal) |
| Servos per arm | 4x MG996R (or DS3218 for metal version) |
| Gripper opening | 0-80mm |
| Stow position | Folded along body sides |
| Control | Manual from phone app + pre-programmed gestures |

### Arm Use Cases

| Use Case | Description |
|---|---|
| Picking up objects | Grab a drink from the fridge, pass items |
| Camera positioning | Mount a GoPro/phone on gripper for unique angles |
| Waving/gestures | Social interaction, wave hello |
| Tool holding | Hold a torch, phone, or sensor for inspection |
| Self-maintenance | Potentially press own buttons, open panels |
| Park interaction | Pick up litter, interact with environment |

### Arm Stowage

```
Driving Mode:                     Deployed:
+--[Arm folded]---------+        +----[Arm extended]-->
|                       |        |
|     Body              |        |     Body
|                       |        |
+--[Arm folded]---------+        +----[Arm extended]-->
```

Arms fold flush against the body sides when not in use. Magnets or spring clips hold them in place during driving. When the rover is in coffee table mode, arms can be fully stowed underneath the deck.

---

## 7. Software Architecture

### Overview

```
+---------------------------------------------------------------+
|                        PHONE APP (PWA)                         |
|  Joystick | Camera | Map | Arms | Settings | Dashboard        |
+------------------------------+--------------------------------+
                               |
                          WebSocket / WebRTC
                               |
+------------------------------+--------------------------------+
|                  JETSON ORIN NANO SUPER (67 TOPS)              |
|  +------------------+  +------------------+  +--------------+ |
|  | ROS2 Core        |  | Web Server       |  | AI Pipeline  | |
|  | - Nav2 stack     |  | - Express/Flask  |  | - YOLO v8    | |
|  | - SLAM           |  | - WebSocket      |  | - Depth      | |
|  | - Sensor fusion  |  | - WebRTC streams |  | - Tracking   | |
|  | - Path planning  |  | - REST API       |  | - OCR/text   | |
|  +------------------+  +------------------+  +--------------+ |
|  +------------------+  +------------------+  +--------------+ |
|  | Camera Manager   |  | Arm Controller   |  | Telemetry    | |
|  | - 7 camera feeds |  | - IK solver      |  | - GPS log    | |
|  | - 360 stitch     |  | - Gesture lib    |  | - Battery    | |
|  | - Recording      |  | - Safety limits  |  | - Speed      | |
|  +------------------+  +------------------+  +--------------+ |
|                               |                                |
|                          UART / I2C                            |
|                               |                                |
+------------------------------+--------------------------------+
|                        ESP32-S3                                |
|  +------------------+  +------------------+  +--------------+ |
|  | Motor Controller |  | Sensor Hub       |  | Safety       | |
|  | - 6x PWM drive   |  | - 6x ultrasonic  |  | - Watchdog   | |
|  | - PCA9685 servos |  | - 6x wheel enc   |  | - E-stop     | |
|  | - PID speed ctrl |  | - BNO055 IMU     |  | - Tilt limit | |
|  | - Cytron MDD10A  |  | - Temp sensors   |  | - Overcurr   | |
|  +------------------+  +------------------+  +--------------+ |
|  +------------------+  +------------------+                    |
|  | LED Controller   |  | Power Monitor    |                    |
|  | - Underglow      |  | - Voltage ADC    |                    |
|  | - Headlights     |  | - Current sense  |                    |
|  | - Status LEDs    |  | - Solar MPPT     |                    |
|  +------------------+  +------------------+                    |
+---------------------------------------------------------------+
```

### ROS2 Node Graph

```
/camera_front ----+
/camera_rear -----+
/camera_left -----+--> /image_stitcher --> /panoramic_view --> /web_server
/camera_right ----+
/camera_mast ---------> /zoom_controller --> /web_server
/camera_depth --------> /depth_processor --> /costmap

/lidar_scan ----------> /slam_node --> /map_server
                             |
                        /amcl_node --> /robot_pose

/gps_node ------+
/imu_node ------+--> /ekf_local  --> /odom (smooth, no GPS jumps)
/wheel_odom ----+        |
                    /ekf_global --> /odom/global (with GPS)
                    /navsat_transform (GPS NavSatFix → odom)

/nav2_controller (RegulatedPurePursuit, DUBIN planner) --> /cmd_vel
  --> /ackermann_controller --> /motor_bridge --> [ESP32 UART]

/ai_detector ------> /object_tracker --> /obstacle_layer --> /costmap

/joystick_input ---> /teleop_node --> /cmd_vel (overrides nav2 in manual mode)

/battery_monitor --> /power_manager --> /auto_return (at 10%)

/weather_station --> /telemetry_publisher --> /web_server

/arm_left_controller --> /arm_ik_solver --> [ESP32 servo commands]
/arm_right_controller -> /arm_ik_solver --> [ESP32 servo commands]

/anti_theft -------> /geofence_monitor --> /alarm_trigger
                                      --> /notification_sender
```

### ESP32-S3 Firmware Architecture

```
main.cpp
  |
  +-- config.h              // Pin definitions, constants
  +-- motor_controller.h    // PID speed control, 6 motors
  +-- steering_controller.h // Servo angles, Ackermann calc
  +-- sensor_hub.h          // Ultrasonic, encoders, IMU
  +-- power_monitor.h       // Battery ADC, current sensing
  +-- led_controller.h      // NeoPixel underglow, headlights
  +-- safety.h              // Watchdog, e-stop, tilt limits
  +-- comms.h               // UART protocol to Jetson
  +-- wifi_fallback.h       // Backup WiFi AP if Jetson down
```

Single translation unit architecture (like Clock/Lamp) — .h files included from main .cpp. Non-blocking state machine ticks throughout (proven pattern from existing projects).

### Communication Protocol (Jetson <-> ESP32)

**Phase 1 (debug/development)**: NMEA-style text protocol at 115200 baud (EA-12)
- Human-readable sentences: `$CMTR,150,-150,200,-200,100,-100*4A`
- 18 message types, ASCII checksum, 50Hz command rate
- Easy to debug via serial monitor or telnet

**Phase 2 (production)**: Binary COBS + CRC-16 at 460800 baud (EA-18)
- Consistent Overhead Byte Stuffing framing (zero-delimiter)
- CRC-16/CCITT error detection, 12% bandwidth utilisation
- Packed C structs with scaled integers (no float)
- Compile-time switch: `#define PHASE2_BINARY_PROTOCOL`

```
Phase 2 message IDs:
Commands (Jetson -> ESP32):
  0x01: Motor speeds (6x int16, ±1000 = ±100%)
  0x02: Steering angles (4x uint16, 0-1800 = 0.0-180.0°)
  0x03: LED control (pattern + RGB)
  0x04: Arm servos (8x uint16)
  0x05: Config set (key-value)
  0x0E: Ping
  0x0F: E-stop (triple-sent for reliability)

Telemetry (ESP32 -> Jetson):
  0x81: Encoder data (6x tick count + dt)
  0x82: IMU data (quaternion + gyro + accel, scaled int16)
  0x83: Ultrasonic distances (6x uint16 mm)
  0x84: Battery status (voltage, current, SoC, temp)
  0x85: System status (mode, errors, uptime)
  0x8E: Pong (response to ping)
  0x8F: E-stop acknowledgement
```

### Phone App (PWA)

Browser-based progressive web app, similar architecture to the existing Hub PWA:

```
Pages/Views:
  /drive          - Live camera + joystick controls
  /cameras        - All camera feeds, 360 view, zoom control
  /map            - GPS map, waypoints, route planning, geofence
  /arms           - Arm control (manual + gestures)
  /dashboard      - Battery, speed, temp, system health
  /settings       - WiFi, control sensitivity, camera quality
  /recordings     - Saved photos/videos
  /autonomy       - Set destinations, patrol routes
  /security       - Anti-theft settings, geofence, alarm

Tech Stack:
  - HTML/CSS/JS (vanilla or lightweight framework)
  - WebSocket for real-time control (<50ms latency)
  - WebRTC for camera streams
  - Gamepad API for physical controller support
  - Service Worker for offline capability
  - Catppuccin Mocha theme (consistent with Hub)
```

### Control Mode State Machine

```
                    +------------+
                    |    BOOT    |
                    +-----+------+
                          |
                    +-----v------+
                    |   IDLE     | <--- Coffee table mode
                    +-----+------+
                          |
              +-----------+-----------+
              |           |           |
        +-----v----+ +---v------+ +--v--------+
        |  MANUAL  | | AUTONOMOUS| |  HYBRID   |
        | Phone    | | GPS/SLAM  | | Auto+     |
        | joystick | | waypoints | | override  |
        +-----+----+ +---+------+ +--+--------+
              |           |           |
              +-----------+-----------+
                          |
                    +-----v------+
                    | RETURNING  |  <--- Auto return-to-home
                    +-----+------+
                          |
                    +-----v------+
                    |  DOCKING   |  <--- Autonomous dock
                    +-----+------+
                          |
                    +-----v------+
                    | CHARGING   |
                    +------------+

Emergency transitions (from any state):
  Any --> E_STOP (physical button or phone kill)
  Any --> TILT_SAFE (IMU detects >45 degree tilt)
  Any --> LOW_BATTERY (10% SOC)
```

### Data Logging & Storage

| Data | Storage | Retention |
|---|---|---|
| GPS tracks | SQLite on Jetson | Permanent, exportable as GPX |
| Camera snapshots | microSD card | Until card full (FIFO) |
| Video recordings | microSD card | Manual delete |
| Sensor telemetry | SQLite | 30 days rolling |
| Maps (SLAM) | Files on Jetson | Permanent |
| Error logs | Text files | 7 days rolling |
| Battery cycles | SQLite | Permanent (health tracking) |

### OTA Updates

| Component | Method |
|---|---|
| Jetson software | SSH + git pull, or rsync from PC |
| ESP32 firmware | OTA via WiFi (same pattern as Clock/Lamp) |
| Phone app | Service worker auto-update (like Hub PWA) |

---

## 8. Accessories

### Mini Fridge

| Parameter | Value |
|---|---|
| Type | Peltier thermoelectric cooler (TEC1-12706) |
| Capacity | ~4-6 cans or 2 bottles |
| Cooling | Ambient -15C to -20C (so ~5C on a 20C day) |
| Power | 12V, 3-5A (36-60W) |
| Location | Centre of body, accessible from top deck |
| Insulation | Foam lined compartment, hinged lid |
| Control | On/off from phone app, temperature display on dashboard |

```
Top deck cutout:
+---------------------------+
|     [Solar]  [Mast]       |
|  +--------+              |
|  | Fridge  | <-- hinged   |
|  | Lid     |    lid       |
|  +--------+              |
|     [Qi Pad]  [Display]   |
+---------------------------+
```

### Phone Charging

| Method | Details |
|---|---|
| Qi wireless pad | Embedded in top deck surface, 15W fast charge |
| USB-C port | Side of body, PD capable, 20W |
| USB-A port | Side of body, 5V 2.4A, for accessories |

### LED System

| Zone | LEDs | Purpose |
|---|---|---|
| Underglow | WS2812B strip (60+ LEDs around body perimeter) | Ambient lighting, status indication |
| Headlights | 2x high-power white LED (3W each) | Front illumination for cameras |
| Tail lights | 2x red LED | Rear visibility |
| Indicators | 4x amber LED (corners) | Turn signals when steering |
| Mast light | 1x RGB LED | Status beacon, visible from distance |
| IR array | 4x IR LED (850nm) | Night vision illumination |

LED Colour Modes:

| Mode | Colour | Pattern |
|---|---|---|
| Manual control | Blue | Steady glow |
| Autonomous | Green | Gentle pulse |
| Hybrid | Cyan | Steady |
| Low battery | Red | Slow flash |
| Charging | Amber | Breathing |
| Docking | White | Fast pulse |
| Coffee table | Warm white (2700K) | Ambient glow |
| Anti-theft alarm | Red | Rapid strobe |
| Party mode | Rainbow | Cycling animation |

### Weather Station

| Sensor | Model | Measurement |
|---|---|---|
| Temperature + humidity | BME280 | -40 to +85C, 0-100% RH |
| Barometric pressure | BME280 (built-in) | 300-1100 hPa |
| Wind speed | Anemometer (cup type) | 0-30 m/s |
| Wind direction | Vane (optional) | 0-360 degrees |
| Rain detector | YL-83 | Rain yes/no + intensity |
| UV index | VEML6075 | UV-A and UV-B |
| Light level | BH1750 | 0-65535 lux |

Location: Weather sensors mounted on mast (wind/rain) and body (temp/pressure/UV/light). Data displayed on dashboard screen and phone app.

### Speaker & Microphone System

| Component | Details |
|---|---|
| Speaker | 2x 3W full-range drivers, sealed enclosure in body |
| Amplifier | MAX98357A I2S amp (Jetson native) |
| Microphone | 2x MEMS mic (SPH0645) for stereo pickup |
| Functions | Two-way audio, voice commands, music playback, alarm siren |

Audio Features:
- Talk through rover from phone (intercom mode)
- Voice command processing (on Jetson or cloud)
- Play music when in coffee table mode (Bluetooth speaker mode)
- Alarm siren for anti-theft (120dB capable with larger driver)
- Startup/shutdown sounds
- Obstacle warning beeps

### Dashboard Display

| Parameter | Value |
|---|---|
| Display | 3.5" or 5" IPS LCD (SPI or HDMI) |
| Location | Rear or side of body, visible when approaching |
| Content | Battery %, speed, GPS coords, temp, mode, IP address |
| Backlight | Auto-dim with light sensor |

```
+---------------------------+
|  ROVER STATUS      12:34  |
|  Battery: 78% ████████░░  |
|  Speed: 2.3 km/h          |
|  GPS: 52.9378, -1.4947    |
|  Temp: 18C  Mode: AUTO    |
|  WiFi: Connected (4G)     |
|  Solar: 45W generating    |
+---------------------------+
```

### Return-to-Home System

```
Trigger: Manual button press OR 10% battery auto-trigger

1. Save current GPS position as "resume point"
2. Load "home" GPS coordinates from saved config
3. Plan route using known map (if available) or GPS waypoints
4. Switch to autonomous navigation
5. Drive to home location using SLAM + GPS fusion
6. Align with docking station using IR beacons or vision
7. Dock and begin charging
8. Send phone notification: "Rover docked and charging"
```

### Docking Station

```
Docking Station (home base):
+---------------------------+
|  [Guide Rails / Ramp]     |
|                           |
|  [Charging Contacts]      |  <-- spring-loaded copper pads
|  [+ positive] [- negative]|     mate with rover underside
|                           |
|  [IR Beacon / ArUco tag]  |  <-- rover aligns visually
|                           |
|  [24V Power Supply]       |
+---------------------------+

Rover underside:
  [Copper contact pads]  <-- recessed, spring-loaded
  Position: centre of belly, aligned with docking station
```

### Anti-Theft System

| Layer | Mechanism | Details |
|---|---|---|
| Geofence | Virtual boundary on map | Configurable polygon, alert if crossed |
| Motion detect | IMU detects movement when parked | Sensitivity adjustable |
| GPS tracking | Position logged every 10s | Viewable on phone map in real-time |
| Alarm | Speaker siren + LED strobe | 120dB capable |
| Phone alert | Push notification | Includes GPS coordinates |
| Motor lock | Software disable + brake | Requires PIN to unlock |
| Kill switch | Remote disable from phone | Rover becomes inert |
| Camera recording | Auto-record all cameras on alarm | Saves to SD card |

---

## 9. Bill of Materials (EA-06 — Research-Backed Costs)

### Phase 1: 0.4 Scale Prototype — $102

| # | Component | Qty | Unit Price | Total |
|---|---|-----|---|---|
| 1 | ESP32-S3 DevKit (N16R8, USB-C) | 1 | $8 | $8 |
| 2 | N20 DC gearmotors (6V, 100RPM, with encoder) | 6 | $3 | $18 |
| 3 | SG90 micro servos (1.8 kg·cm) | 4 | $2 | $8 |
| 4 | L298N motor drivers (dual H-bridge) | 2 | $3 | $6 |
| 5 | 2S LiPo 2200mAh (7.4V, XT30) | 1 | $12 | $12 |
| 6 | LiPo charger (2S balance) | 1 | $8 | $8 |
| 7 | PLA filament (1kg spool) | 1 | $20 | $20 |
| 8 | 608ZZ bearings | 12 | $0.50 | $6 |
| 9 | M3 fastener set + heat-set inserts | 1 set | $9 | $9 |
| 10 | Breadboard + jumper wires + switch | 1 | $8 | $8 |
| | **Phase 1 Total** | | | **$102** |

### Phase 2: Full-Scale 3D Printed — $1,482.50 (+10% contingency = $1,630.75)

| Category | Items | Subtotal |
|---|---|---|
| Compute & Electronics | Jetson Orin Nano Super ($249), ESP32-S3, PCA9685, USB hub, 2× microSD | $292 |
| Cameras & Vision | 4× Arducam 120° ($60), ELP 10× zoom ($50), OAK-D Lite ($89), Pi NoIR ($25), IR LEDs ($5) | $229 |
| Navigation Sensors | RPLidar A1 ($73), BN-220 GPS ($12), BNO055 IMU ($15), 6× HC-SR04 ($9) | $109 |
| Drivetrain | 6× Chihai 37mm 80RPM w/encoder ($72), 3× Cytron MDD10A ($45), 4× MG996R ($24) | $141 |
| Arms & Mast | 8× MG996R arm ($48), 2× MG996R mast ($12), slip ring ($8) | $68 |
| Power System | 2× Turnigy 6S 10Ah 12C ($100), 2× BMS ($16), charger ($20), converters ($17), wiring ($32) | $185 |
| Solar | 4× 25W panels ($80), CN3722 MPPT ($15), hinges ($8) | $103 |
| Accessories | Fridge ($15), Qi charger ($8), USB ports ($6), LEDs ($15), speakers ($10), weather sensors ($20), display ($12), INA219×4 ($8), DS18B20×3 ($4.50) | $96.50 |
| Structure & Hardware | 4× PETG 1kg ($60), 6× 2020 extrusion ($24), brackets ($10), T-nuts ($7.50), bearings ($9.50), fasteners ($20), connectors ($13), cable ties ($5) | $234 |
| Docking Station | Copper contacts ($8), 24V PSU ($12), base plate ($5) | $25 |
| | **Phase 2 Total** | **$1,482.50** |
| | **+ 10% Contingency** | **$1,630.75** |

### Phase 3: Metal Build (Additional) — $260 (+15% contingency = $299)

| Item | Cost |
|---|---|
| Aluminium sheet (1.5mm, 2m²) | $60 |
| Aluminium rectangular tube (rocker/bogie arms) | $25 |
| Steel rod (axles, differential bar) | $15 |
| 4× DS3218 upgraded steering servos | $40 |
| 6001-2RS sealed bearings | $15 |
| Paint / powder coat / anodising | $30 |
| Weatherproof gaskets + cable glands (IP54) | $15 |
| Tempered glass top panel (optional) | $25 |
| Stainless steel fasteners upgrade | $15 |
| Machining consumables (drill bits, taps) | $20 |
| **Phase 3 Additional** | **$260 (+$39 contingency = $299)** |

### Total Project Budget

| Phase | Components | Contingency | Budget Total |
|---|---|---|---|
| Phase 1 (0.4 prototype) | $102 | included | $102 |
| Phase 2 (full 3D print) | $1,482.50 | $148.25 | $1,630.75 |
| Phase 3 (metal, additional) | $260 | $39 | $299 |
| **Grand Total** | **$1,844.50** | **$187.25** | **$2,031.75** |

**$2,031.75 slightly exceeds the $1,500-2,000 target budget** by ~$32. This is due to revised filament estimates (EA-08, EA-11, EA-17). Consider the cost reduction options in EA-06 or a modest budget adjustment. If budget is tight, core rover (compute + cameras + drivetrain + power + structure) works for **$764** — everything else can be added incrementally.

---

## 10. Build Phases — Detailed

### Phase 1: 0.4 Scale Prototype

**Goal**: Prove rocker-bogie geometry works, basic driving, validate dimensions.

**What gets tested**:
- Rocker-bogie suspension articulation over obstacles
- Motor torque vs weight ratio
- Steering geometry (Ackermann, point turn, crab)
- Basic ESP32 motor control firmware
- 3D print assembly method (bolt-together segments)
- Wheel grip on grass, gravel, slopes

**What does NOT go in Phase 1**:
- No Jetson (ESP32 only)
- No cameras (except optional ESP32-CAM for fun)
- No arms, no mast
- No fridge, no charging, no weather
- No AI, no LIDAR, no GPS
- Simple RC control from phone via WiFi (web server on ESP32)

**Print segments** (225x145mm bed):
- Chassis: ~6-8 segments (body is ~440x260mm at 0.4 scale)
- Rocker arms: 2x (each fits in one print)
- Bogie arms: 2x (each fits in one print)
- Wheels: 6x (each ~80mm diameter, one per print)
- Differential bar: 1x
- Total: ~15-20 prints, estimated 40-60 hours print time

### Phase 2: Full-Scale 3D Printed

**Goal**: Full electronics integration, all features working, software complete.

**Print segments** (225x145mm bed, body is 1100x650mm):
- Top deck: ~25-30 panels (220x130mm each, 2 layers of panels)
- Side panels: ~12 panels
- Electronics bay: ~8 panels
- Rocker arms: 4 segments each (reinforced with aluminium rod)
- Bogie arms: 2 segments each
- Wheels: 6x (printed in halves, bolted together)
- Mast: 3-4 sections (telescoping)
- Arm segments: ~12 pieces (6 per arm)
- Fridge housing: 4 panels
- Camera mounts: 7x custom brackets
- Total: ~80-100 prints, estimated 200-300 hours print time

**Reinforcement strategy**:
- 2020 aluminium extrusion as skeleton (bolted to printed panels)
- Aluminium rods through rocker/bogie arms for strength
- Metal wheel axles with printed hubs
- Steel bolts at all stress points

### Phase 3: Metal Build

**Goal**: Production quality, weatherproof, long-term durability.

**Machining required**:
- Wheel hubs: lathe (aluminium)
- Axles: lathe (steel)
- Rocker/bogie arms: mill or waterjet (aluminium plate)
- Chassis frame: welded aluminium box section or extrusion
- Body panels: sheet aluminium, bent/formed
- Custom brackets: mill

**3D printed parts retained**:
- Camera housings (complex geometry, low stress)
- Fridge insulation housing
- Cable management clips
- Dashboard display bezel
- Gripper fingers
- Decorative elements (cleats, logos)

---

## 11. Risk Register

| # | Risk | Impact | Likelihood | Mitigation |
|---|---|---|---|---|
| 1 | Rocker-bogie too complex to print | High | Medium | Phase 1 validates at small scale first |
| 2 | Weight exceeds motor torque | High | Medium | Calculate torque requirements, size motors accordingly |
| 3 | Battery life insufficient | Medium | Low | 444Wh is generous; solar extends runtime |
| 4 | 3D printed parts break under load | High | Medium | Aluminium extrusion skeleton, Phase 3 replaces with metal |
| 5 | Jetson overheats outdoors | Medium | Medium | Heatsink + fan, thermal throttling, shade from solar panels |
| 6 | WiFi range insufficient at park | Medium | High | 4G modem as backup, antenna on mast |
| 7 | Rain damages electronics | High | Medium | IP54 sealing in Phase 3, weather awareness in software |
| 8 | Budget overrun | Medium | Medium | Phase 1 is cheap validation; buy Phase 2 incrementally |
| 9 | LIDAR SLAM too complex | Low | Medium | Start with GPS-only nav, add SLAM incrementally |
| 10 | Theft at park | High | Low | GPS tracking, alarm, geofence, motor lock, camera recording |
| 11 | Peltier fridge draws too much power | Low | Low | Software-controlled, only runs when stationary/charging |
| 12 | Print time too long (300hrs) | Low | High | Print in parallel batches, accept timeline |

---

## 12. Next Steps

1. **Install Fusion 360** — download and set up for CAD modelling
2. **Design Phase 1 prototype in CAD** — use dimensions from EA-08, rocker-bogie geometry first
3. **Simulate suspension** — test articulation range in Fusion 360
4. **Print Phase 1 parts** — follow EA-08 §13.3 print order, EA-11 for settings
5. **Order Phase 1 electronics** — ESP32-S3, N20 motors, SG90 servos, L298N drivers ($102, EA-06)
6. ~~**Write ESP32 firmware**~~ — ✅ DONE: `firmware/esp32/` — motor control + WiFi web server + Ackermann steering
7. **Assemble and test** — follow EA-08 §14 assembly sequence, calibrate servos

---

---
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

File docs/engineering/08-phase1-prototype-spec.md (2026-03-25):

# Engineering Analysis 08: Phase 1 Prototype Parts Specification

**Document**: EA-08
**Date**: 2026-03-15
**Purpose**: Define exact dimensions, print specifications, and assembly details for every component of the 0.4-scale prototype rover, providing sufficient detail for CAD modelling and 3D printing.
**Depends on**: EA-01 (Suspension), EA-02 (Drivetrain), EA-05 (Weight Budget), EA-06 (Cost)

---

## 1. Phase 1 Overview
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

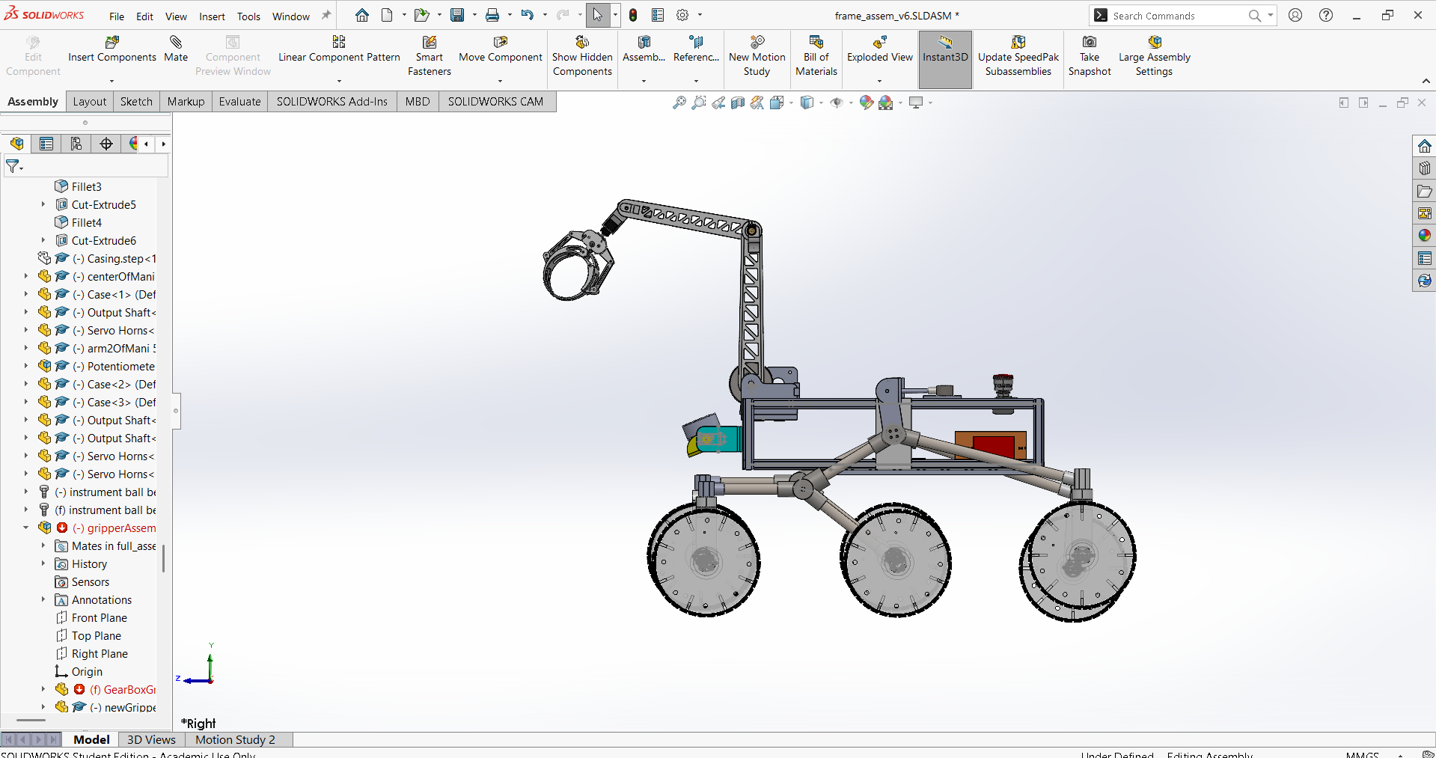
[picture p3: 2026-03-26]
cad/reference-suspension/Screenshot 2025-08-29 094610.png

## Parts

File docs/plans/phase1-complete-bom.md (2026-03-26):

# Phase 1 Complete Bill of Materials

Every single part needed to build the 0.4-scale Mars Rover prototype.
Updated to reflect EA-25/26 tube+connector suspension and EA-27 steering.

---

## A. 3D PRINTED PARTS (PLA on CTC Bizer)

### A1. Calibration & Test Pieces (print first)
| Part | Qty | Dimensions (mm) | Print Time | Weight Est |
|---|-----|---|---|---|
| CalibrationTestCard | 1 | 50 × 50 × 5 | 15min | 5g |
| BearingTestPiece | 1 | 33 × 33 × 12 | 20min | 6g |
| TubeSocketTest | 1 | 30 × 25 × 30 | 15min | 5g |

Purpose: Validate printer calibration, bearing press-fit (22.15mm bore), and 8mm tube socket (8.2mm bore) before committing to real parts.
Total: 3 pieces, ~50min print, ~16g PLA

### A2. Wheels
| Part | Qty | Dimensions (mm) | Print Time | Weight Est |
|---|-----|---|---|---|
| RoverWheelV3 | 6 | 86 OD × 32 wide (over grousers) | 2hr ea | 20g ea |
| RoverTire (TPU) | 6 | 86 OD × 70 bore × 32 wide | 1hr ea | 10g ea |

Features per wheel: 3.1mm D-shaft bore, M2 grub screw, 3× O-ring grooves, 12× grousers, 5 spokes
Tires: TPU 95A, requires friend's TPU-capable printer. Fallback: O-rings in wheel grooves.
Total: 6 wheels + 6 tires, ~18hr print, ~180g PLA + 60g TPU

### A3. Steering System (EA-27)
| Part | Qty | Dimensions (mm) | Print Time | Weight Est |
|---|-----|---|---|---|
| SteeringBracket | 4 | 35 × 30 × 25 | 45min ea | 12g ea |
| SteeringKnuckle | 4 | 25 × 30 × 35 | 30min ea | 8g ea |
| SteeringHornLink | 4 | 20 × 8 × 5 | 10min ea | 2g ea |
| ServoMount | 4 | 40 × 15 × 25 | 20min ea | 5g ea |

SteeringBracket: 608ZZ bearing seat (top), 8mm pivot bore (through), hard stop walls (±35°), 2× M3 clearance through-holes. Bolts to connector face.
SteeringKnuckle: Tapered body, 8mm pivot shaft bore (top), N20 motor clip (bottom), steering arm + hard stop tab.
SteeringHornLink: 20mm c/c 4-bar link, 2× M2 pin holes. Connects servo horn to knuckle steering arm.
ServoMount: SG90 pocket (22.4×12.2×12mm), horn slot (12mm), 2× M3 heat-set inserts on bottom face.
Total: 16 pieces, ~7hr print, ~108g PLA

### A4. Drivetrain
| Part | Qty | Dimensions (mm) | Print Time | Weight Est |
|---|-----|---|---|---|
| FixedWheelMount | 2 | 30 × 25 × 28 | 30min ea | 8g ea |

Features: N20 motor clip, 2× M3 clearance through-holes. Bolts to middle wheel connector face.
Locations: ML, MR (middle wheels — not steered)
Total: 2 mounts, ~1hr print, ~16g PLA

### A5. Suspension Connectors (EA-25/26 tube+connector approach)
| Part | Qty | Dimensions (mm) | Print Time | Weight Est |
|---|-----|---|---|---|
| RockerHubConnector | 2 | 55 × 45 × 45 | 1.5hr ea | 25g ea |
| BogiePivotConnector | 2 | 55 × 45 × 35 | 1hr ea | 20g ea |
| FrontWheelConnector | 4 | 35 × 30 × 45 | 45min ea | 12g ea |
| MiddleWheelConnector | 2 | 30 × 30 × 45 | 40min ea | 10g ea |
| DifferentialPivotHousing | 1 | 50 × 45 × 40 | 1.5hr | 25g |
| DifferentialLink | 2 | 30 × 12 × 8 | 10min ea | 3g ea |
| CableClip | 12 | 18 × 12 × 10 | 5min ea | 1g ea |

RockerHubConnector: Hub body with 608ZZ bearing seat (rocker pivot), 3× tube sockets (8.2mm bore × 15mm deep) for front/rear/up tubes, M3 heat-set inserts, wire channel. Mounts on diff bar.
BogiePivotConnector: 608ZZ bearing seat (bogie pivot), 2× tube sockets (front/rear), wire channel. At rocker-bogie junction.
FrontWheelConnector: Tube socket (from bogie), bearing-mount face with M3 heat-set inserts for steering bracket. At FL/FR/RL/RR corners.
MiddleWheelConnector: Tube socket (from bogie), motor-mount face with M3 heat-set inserts for fixed wheel mount. At ML/MR.
DifferentialPivotHousing: 608ZZ bearing seat (diff bar pivot), mounts under body centre. Diff bar passes through.
DifferentialLink: Through-bar linkage rod with M3 rod-end bearing holes at each end. Connects diff bar to rocker hubs (EA-26).
CableClip: Snap-on cable management for 8mm tubes. 6mm U-channel, M3 attachment hole.
Total: 25 pieces, ~13hr print, ~180g PLA

### A6. Body Frame
| Part | Qty | Dimensions (mm) | Print Time | Weight Est |
|---|-----|---|---|---|
| BodyQuadrant FL | 1 | 130 × 220 × 120 | 8hr | 80g |
| BodyQuadrant FR | 1 | 130 × 220 × 120 | 8hr | 80g |
| BodyQuadrant RL | 1 | 130 × 220 × 120 | 10hr | 95g |
| BodyQuadrant RR | 1 | 130 × 220 × 120 | 10hr | 95g |

Features: 4mm walls, internal ribs, rocker pivot bosses, cable channels, vent slots, tongue-and-groove seams, alignment dowels (3mm), heat-set insert pockets, LED holes, headlight/taillight holes. Kill switch hole on RR only.
Y-split at Y=0 — all 4 quadrants ~130×220mm, fits 225×145mm CTC Bizer bed.
Total: 4 quadrants, ~36hr print, ~350g PLA

### A7. Top Deck
| Part | Qty | Dimensions (mm) | Print Time | Weight Est |
|---|-----|---|---|---|
| TopDeck FL | 1 | 130 × 220 × 3 | 1hr | 15g |
| TopDeck FR | 1 | 130 × 220 × 3 | 1hr | 15g |
| TopDeck RL | 1 | 130 × 220 × 3 | 1hr | 15g |
| TopDeck RR | 1 | 130 × 220 × 3 | 1hr | 15g |

Features: 3mm panel + edge lips, snap clips on seam edges, stiffening ribs (underside). FR tile has phone holder mounting bosses (M3 heat-set inserts).
Total: 4 tiles, ~4hr print, ~60g PLA

### A8. Internal Components
| Part | Qty | Dimensions (mm) | Print Time | Weight Est |
|---|-----|---|---|---|
| ElectronicsTray | 1 | 120 × 180 × 18 | 3hr | 40g |
| BatteryTray | 1 | 94 × 42 × 23 | 1hr | 15g |
| StrainReliefClip | 10 | 18 × 10 × 11.5 | 10min ea | 2g ea |
| FuseHolderBracket | 1 | 15 × 40 × 12 | 15min | 4g |
| SwitchMount | 1 | 30 × 30 × 5 | 15min | 3g |

ElectronicsTray: ESP32 edge-clip cradle, 2× L298N standoffs, breadboard standoffs, wire channels, cable exits.
BatteryTray: 86×34×19mm LiPo cradle, strap slots, XT60+JST-XH access cutouts, corner gussets.
StrainReliefClip: U-channel (6mm wide × 5mm deep), snap tab, 2× M3 holes. At cable routing points.
FuseHolderBracket: 8mm clip channel, 2× M3 mounting holes.
SwitchMount: 15mm centre bore, 2× M3 diagonal holes. Inside RR body quadrant.
Total: 14 pieces, ~6hr print, ~82g PLA

---

### PRINTED PARTS SUMMARY
| Category | Parts | Total Print Time | Total PLA |
|---|---|---|---|
| Calibration/test | 3 | 50min | 16g |
| Wheels (PLA rims) | 6 | 12hr | 120g |
| Steering system | 16 | 7hr | 108g |
| Drivetrain (fixed mounts) | 2 | 1hr | 16g |
| Suspension connectors | 25 | 13hr | 180g |
| Body quadrants | 4 | 36hr | 350g |
| Top deck tiles | 4 | 4hr | 60g |
| Internal components | 14 | 6hr | 82g |
| TPU tires (friend's printer) | 6 | ~6hr | 60g TPU |
| **TOTAL PLA** | **74 parts** | **~80hr** | **~932g** |
| **TOTAL TPU** | **6 tires** | **~6hr** | **~60g** |

**PLA needed: 2× 1kg spools** (~932g parts + ~350g supports/brim/waste/test prints = ~1282g total)
**TPU needed: 250g spool** (60g tires + margin for test prints)

---

## B. BEARINGS

| Part | Size | Qty | Purpose | Location |
|---|---|-----|---|---|
| 608ZZ | 8×22×7mm | 1 | Left rocker body pivot | RockerHubConnector L |
| 608ZZ | 8×22×7mm | 1 | Right rocker body pivot | RockerHubConnector R |
| 608ZZ | 8×22×7mm | 1 | Left rocker-bogie pivot | BogiePivotConnector L |
| 608ZZ | 8×22×7mm | 1 | Right rocker-bogie pivot | BogiePivotConnector R |
| 608ZZ | 8×22×7mm | 1 | Diff bar centre pivot | DifferentialPivotHousing |
| 608ZZ | 8×22×7mm | 1 | Steering pivot FL | SteeringBracket FL |
| 608ZZ | 8×22×7mm | 1 | Steering pivot FR | SteeringBracket FR |
| 608ZZ | 8×22×7mm | 1 | Steering pivot RL | SteeringBracket RL |
| 608ZZ | 8×22×7mm | 1 | Steering pivot RR | SteeringBracket RR |
| **TOTAL** | | **9** | | |

**Note**: EA-26 through-bar diff mechanism — no bearings at diff bar ends (DifferentialLinks use M3 rod-end bearings instead). Buy 12 (9 + 3 spares).

---

## C. MOTORS

| Part | Qty | Specs | Purpose |
|---|-----|---|---|
| N20 gearmotor 100RPM | 6 | 12×10×24mm (15mm can + 9mm gearbox), 3mm D-shaft, 6V, ~10g | Wheel drive (×6) |
| SG90 micro servo | 4 | 22.2×11.8×22.7mm, 9g, 1.8 kg-cm at 4.8V | Steering (FL, FR, RL, RR) |

---

## D. FASTENERS

### D1. M8 (Pivot Bolts)
| Part | Qty | Purpose |
|---|-----|---|
| M8 × 40mm hex bolt | 4 | Rocker + bogie pivot shafts |
| M8 × 30mm hex bolt | 4 | Steering pivot shafts |
| M8 nyloc nut | 8 | Lock all M8 pivots |
| M8 flat washer | 16 | 2 per pivot (both sides) |

### D2. M3 (General Assembly)
| Part | Qty | Purpose |
|---|-----|---|
| M3 × 12mm socket cap | 34 | Body joins, standoffs, brackets, connector bolting |
| M3 × 8mm socket cap | 20 | Electronics, motor clips |
| M3 nut | 30 | General |
| M3 flat washer | 30 | General |
| M3 × 5mm brass heat-set insert | 40 | 5.7mm OD, knurled — in connectors, body, servo mounts |

### D3. M2 (Small Fasteners)
| Part | Qty | Purpose |
|---|-----|---|
| M2 × 8mm pan head | 8 | SG90 servo mounting (4 servos × 2) |
| M2 × 4mm grub/set screw | 6 | Wheel hub shaft retention |
| M2 × 10mm socket cap | 8 | Steering horn link pin joints (EA-27) |
| M2 nyloc nut | 8 | Horn link pin retention (EA-27) |
| M2 nylon flat washer | 16 | Horn link smooth rotation (EA-27) |

### D4. Alignment
| Part | Qty | Purpose |
|---|-----|---|
| 3mm × 20mm steel dowel pin | 4 | Body quadrant alignment |

---

## E. STRUCTURAL HARDWARE

| Part | Qty | Specs | Purpose |
|---|-----|---|---|
| 8mm steel rod | 2 | 1m lengths — cut to: 1×400mm (diff bar), 2×150mm (rocker front), 6×60mm (rocker rear + bogie) | Suspension tube framework |
| M3 rod-end bearing (heim joint) | 4 | Ball joint, M3 thread | Differential links (2 links × 2 ends, EA-26) |
| M3 × 20mm bolt | 4 | | Through-bolt for rod-end bearings to diff link ends |
| 8mm shaft collar | 4 | Bore 8mm, set screw | Retain diff bar + rocker pivot shafts |
| Rubber O-ring | 18 | 70mm ID × 3mm cross-section | Wheel traction bands (3/wheel) — only if NOT using TPU tires |
| 100nF ceramic capacitor | 7 | | Motor noise suppression (6× motor + 1× ADC) |

**Rod cutting plan** (from 2× 1m rods):
| Rod | Cut | Length | Purpose |
|-----|-----|---|---|
| Rod 1 | 1 | 400mm | Differential bar |
| Rod 1 | 2-3 | 2× 150mm | Left + right rocker front tubes |
| Rod 1 | 4-6 | 3× 60mm | Rocker rear + bogie short tubes |
| Rod 2 | 1-3 | 3× 60mm | Remaining bogie short tubes |
| Rod 2 | - | 820mm spare | Future use |

Total: 9 tube pieces, ~1060mm from 2000mm stock.

---

## F. ELECTRONICS

| Part | Qty | Specs | Purpose |
|---|-----|---|---|
| ESP32-S3 DevKitC-1 N16R8 | 1 | 63×25mm, USB-C | Main controller |
| L298N motor driver | 2 | 43×43×27mm | 3 motors each |
| 2S LiPo battery | 1 | 7.4V 2200mAh, 86×34×19mm | Power |
| XT60 connector pair | 1 | | Battery connection |
| Toggle switch | 1 | 15mm panel mount | Main power |
| E-stop tactile button | 1 | Momentary, NC, panel mount | Emergency stop (EA-15) |
| 5A mini blade fuse | 1 | ATC/ATO standard | Overcurrent protection |
| 5V 3A buck converter (XL4015) | 1 | Input 7-35V, output 5V 3A | Dedicated servo power (EA-19) |
| LED (green) | 1 | 3mm or 5mm | Power indicator |
| Resistor 330 ohm | 1 | 1/4W | LED current limit |
| Mini breadboard | 1 | 47×35mm | Prototyping connections |
| Dupont jumper wires | 40 | M-M and M-F mix | Connections |
| JST-XH connectors | 6 | 2-pin | Motor connections |
| 22AWG silicone wire | 3m | Red, black, colours | Power + signal |

---

## G. WIRING

| Connection | Wire | Length Est | Notes |
|---|---|---|---|
| Battery → switch | 18AWG | 150mm | High current path |
| Switch → L298N × 2 | 18AWG | 200mm ea | Power distribution |
| L298N → motors × 6 | 22AWG | 300mm ea | Through cable channels + tubes |
| ESP32 → L298N × 2 | 22AWG signal | 150mm ea | PWM + direction |
| ESP32 → servos × 4 | 22AWG signal | 250mm ea | PWM signal |
| Servo power | 22AWG | 200mm | From 5V buck converter to servo rail |
| Buck converter input | 18AWG | 150mm | Battery rail → XL4015 input |
| Battery voltage divider | Resistors | On breadboard | ADC monitoring |

---

## H. CONSUMABLES & SUNDRIES

| Part | Qty | Purpose | Notes |
|---|-----|---|---|
| Small zip ties (100mm) | 20+ | Wire bundle management | At strain relief clips, tube junctions |
| Velcro cable ties | 10+ | Reusable wire management | Inside body, battery strap |
| Hot glue sticks (7mm) | 5+ | Strain relief, connector securing | Requires hot glue gun |

---

## I. OPTIONAL / RECOMMENDED

| Part | Qty | Purpose | Priority |
|---|-----|---|---|
| Loctite threadlock (blue) | 1 | M8 nyloc backup | Medium |
| Cyanoacrylate (super glue) | 1 | Emergency repairs | Low |
| Soldering iron (for heat-sets) | 1 | Insert installation | HIGH |
| Digital calipers | 1 | Calibration measurement | HIGH |
| 608ZZ bearing (spare) | 3 | In case of fit issues | Medium |
| PLA filament 1kg spool | 1 | Fresh, sealed | HIGH |
| SD card 8GB+ (for CTC Bizer) | 1 | x3g file transfer | HIGH |
| USB-C data cable (1m+) | 1 | ESP32-S3 programming | HIGH |

---

## COST ESTIMATE

| Category | Est Cost (GBP) |
|---|---|
| 608ZZ bearings (×12 inc spares) | £8 |
| N20 motors (×6) | £18 |
| SG90 servos (×4) | £8 |
| M8 hardware kit | £5 |
| M3 hardware kit + heat-set inserts | £12 |
| M2 hardware kit (grub + servo + horn link) | £5 |
| 3mm dowel pins (×4) | £2 |
| Steel rod 8mm × 1m (×2) | £6 |
| Shaft collars (×4) | £3 |
| Rod-end bearings M3 (×4) | £3 |
| O-rings (×20) (only if no TPU) | £4 |
| ESP32-S3 DevKitC-1 | £12 |
| L298N drivers (×2) | £6 |
| 5V 3A buck converter | £3 |
| E-stop + LED + resistor | £1.50 |
| 2S LiPo 2200mAh | £12 |
| Wire, connectors, misc | £8 |
| PLA filament 2× 1kg | £28 |
| SD card 8GB | £4 |
| USB-C data cable | £3 |
| **TOTAL** | **~£153** |

---

## ASSEMBLY ORDER

1. Print calibration pieces → calibrate CTC Bizer
2. Print & test-fit: 1 bearing test + 1 tube socket test → verify 608ZZ and 8mm rod fit
3. Print 1 wheel + 1 steering bracket → test-fit with N20 motor and 608ZZ bearing
4. Print all wheels (×6)
5. Print steering: brackets (×4) + knuckles (×4) + horn links (×4) + servo mounts (×4)
6. Print drivetrain: fixed wheel mounts (×2)
7. Cut 8mm rods to length (9 pieces from 2× 1m rods)
8. Print suspension connectors: rocker hub (×2) + bogie pivot (×2) + wheel connectors (×4+2)
9. Print diff housing (×1) + diff links (×2) + cable clips (×12)
10. Sub-assemble: wheels + motors + brackets/knuckles on connectors
11. Sub-assemble: bogie arms (tube + connectors + middle/rear wheels)
12. Sub-assemble: rocker arms (tube + connectors + front wheel + bogie)
13. Install diff bar + bearings + links
14. Print body quadrants (×4) — longest print batch (~36hr)
15. Print top deck tiles (×4)
16. Join body quadrants with dowels + M3 bolts
17. Install suspension into body via rocker pivot bearings
18. Print & install electronics tray + battery tray
19. Print accessories: strain relief (×10) + fuse bracket + switch mount
20. Wire everything (EA-19, EA-23)
21. Flash firmware
22. Test drive!

---

*Phase 1 BOM v2.0 — 2026-03-26 — Updated for EA-25/26/27 tube+connector design*

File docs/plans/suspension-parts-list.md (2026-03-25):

# Suspension Assembly — Complete Parts List

**Version:** 1.0
**Date:** 2026-03-24
**Status:** DESIGN DRAFT — for review and iteration

## Design Philosophy

Inspired by [jakkra/Mars-Rover](https://github.com/jakkra/Mars-Rover) and NASA [Perseverance](https://newscrewdriver.com/2020/11/21/perseverance-rover-interactive-3d-model/):

- **Metal tubes with printed connectors** (like jakkra's PVC approach) for structural arms
- **Printed joints** house bearings and provide attachment/pivot points
- **Perseverance-style wheels** with curved spokes and angled grousers
- **608ZZ bearings** at all pivot points (proven, cheap, available)

### Why Tubes + Printed Connectors?

| Property | Fully Printed Arms | Tube + Connector |
|---|---|---|
| Strength | Limited (PLA layer adhesion) | Excellent (metal tube in tension/compression) |
| Weight | Heavier (solid infill needed) | Lighter (hollow tube) |
| Stiffness | Moderate | Very high |
| Print time | Long (180mm arms) | Short (just connectors) |
| Adjustability | None (reprint to resize) | Cut tubes to length |
| Aesthetics | Okay | NASA-like (visible tubes) |
| Assembly | Bolt together | Press-fit + grub screw |

---

## Part Categories

### A. PRINTED PARTS (PLA, CTC Bizer)

#### A1. Suspension Connectors (NEW — replace monolithic arms)

| # | Part | Qty | Description | Key Features |
|---|---|-----|---|---|
| 1 | **Rocker Hub Connector** | 2 | Central joint where rocker meets body (diff bar pivot) | 608ZZ bearing seat, 8mm tube socket ×2 (front + rear), M3 heat-set ×4, diff bar bore |
| 2 | **Bogie Pivot Connector** | 2 | Joint where bogie arm meets rocker arm rear | 608ZZ bearing seat, 8mm tube socket ×3 (rocker rear + bogie front + bogie rear), M3 heat-set ×4 |
| 3 | **Front Wheel Connector** | 2 | End of rocker front tube, mounts steering bracket | 8mm tube socket ×1, steering bracket mount (M3 heat-set ×2), servo mount tab |
| 4 | **Middle Wheel Connector** | 2 | End of bogie front tube, mounts fixed wheel mount | 8mm tube socket ×1, motor mount (M3 heat-set ×2) |
| 5 | **Rear Wheel Connector** | 2 | End of bogie rear tube, mounts steering bracket | 8mm tube socket ×1, steering bracket mount (M3 heat-set ×2), servo mount tab |

**Connector design notes:**
- Each connector has a **socket** for the 8mm tube: 8.2mm bore × 15mm deep (0.2mm clearance)
- Tube is secured with a **M3 grub screw** through the connector wall into the tube
- Wall thickness around tube socket: 4mm minimum (structural)
- Bearing seats: 22.15mm bore × 7.2mm deep (standard 608ZZ, as per CAD audit)
- Material: PLA, 60% infill, 5 perimeters

#### A2. Steering & Drive Components (existing designs, may need socket adapters)

| # | Part | Qty | Description | Script |
|---|---|-----|---|---|
| 6 | **Steering Bracket** | 4 | Corner wheel pivot housing (608ZZ + N20 motor clip) | `steering_bracket.py` |
| 7 | **Servo Mount** | 4 | SG90 servo bracket, drives steering rotation | `servo_mount.py` |
| 8 | **Fixed Wheel Mount** | 2 | Middle wheel motor mount (no steering) | `fixed_wheel_mount.py` |

#### A3. Drivetrain

| # | Part | Qty | Description | Script |
|---|---|-----|---|---|
| 9 | **Differential Pivot Housing** | 1 | Body-mounted housing for diff bar pivot bearing | `differential_pivot_housing.py` |

#### A4. Wheels

| # | Part | Qty | Description | Script |
|---|---|-----|---|---|
| 10 | **Rover Wheel V3** | 6 | 80mm OD, Perseverance-style curved spokes, 24 grousers | `rover_wheel_v3.py` |
| 11 | **Rover Tire** | 6 | TPU 95A tire (86mm OD, 70mm bore) — Phase 2 / friend's printer | `rover_tire.py` |

#### A5. Body (not part of suspension, but connects to it)

| # | Part | Qty | Description |
|---|---|-----|---|
| 12 | Body Quadrant | 4 | FL/FR/RL/RR panels (diff bar passes through rocker pivot bosses) |
| 13 | Top Deck Tile | 4 | FL/FR/RL/RR covers |

**Total printed parts for suspension: 27** (10 connectors + 4 steering + 4 servo + 2 fixed mount + 3 diff adapter + 6 wheels)
_Reduced from 33 if you count the old monolithic arms (2 rocker front + 2 rocker rear + 2 bogie = 6 arms eliminated, replaced by 10 smaller connectors)_

---

### B. HARDWARE — Metal Tubes & Rods

#### B1. Structural Tubes (8mm steel rod or aluminium tube)

| # | Part | Qty | Length | Description |
|---|---|-----|---|---|
| 1 | **Rocker Front Tube** | 2 | ~165mm | Rocker hub connector → front wheel connector |
| 2 | **Rocker Rear Tube** | 2 | ~75mm | Rocker hub connector → bogie pivot connector |
| 3 | **Bogie Front Tube** | 2 | ~75mm | Bogie pivot connector → middle wheel connector |
| 4 | **Bogie Rear Tube** | 2 | ~75mm | Bogie pivot connector → rear wheel connector |
| 5 | **Differential Bar** | 1 | 300mm | 8mm steel rod, spans full width (existing design) |

**Tube options:**
- **8mm steel rod** (current design): cheap, strong, heavy. Socket = 8.2mm bore.
- **8mm OD aluminium tube** (6mm ID): lighter, weaker but sufficient at 0.4 scale. Same sockets.
- **10mm OD aluminium tube** (8mm ID): better for grip, needs wider sockets.
- **6mm carbon fibre rod**: lightest, most expensive. Very stiff.

**Recommendation for Phase 1:** 8mm steel rod (consistency with diff bar, cheapest, readily available from hardware store). Cut to length with hacksaw.

**Total tube length needed:** 2×165 + 4×75 + 300 = 930mm ≈ 1m of 8mm rod

#### B2. Bearings

| # | Part | Qty | Location | Spec |
|---|---|-----|---|---|
| 1 | 608ZZ | 2 | Rocker body pivot (L+R) | 22×8×7mm |
| 2 | 608ZZ | 2 | Bogie pivot (L+R) | 22×8×7mm |
| 3 | 608ZZ | 1 | Diff bar body pivot | 22×8×7mm |
| 4 | 608ZZ | 4 | Steering pivots (4 corners) | 22×8×7mm |
| **Total** | **608ZZ** | **9** | | **buy 12 (3 spare) ~£5** |

#### B3. Fasteners

| # | Part | Qty | Use |
|---|---|-----|-----|
| 1 | M3 × 8mm bolt | 30 | Connector assembly, bracket mounting |
| 2 | M3 × 12mm bolt | 10 | Through-connector joints |
| 3 | M3 heat-set insert (4.8mm × 5.5mm) | 40 | All printed connector sockets |
| 4 | M3 grub screw (set screw) | 8 | Tube retention in connectors |
| 5 | M2 × 6mm bolt | 8 | Servo tab mounting (4 servos × 2 screws) |
| 6 | M2 grub screw | 6 | Wheel shaft retention |
| 7 | 8mm shaft collar / E-clip | 10 | Axial retention on 8mm rods |

#### B4. 8mm Shafts (Axle Pins)

| # | Part | Qty | Length | Use |
|---|---|-----|---|-----|
| 1 | 8mm steel pin | 2 | 35mm | Rocker body pivot axle |
| 2 | 8mm steel pin | 2 | 35mm | Bogie pivot axle |
| 3 | 8mm steel pin | 4 | 20mm | Steering pivot axle (through steering bracket bearing) |

---

### C. ELECTRONICS

| # | Part | Qty | Use |
|---|---|-----|-----|
| 1 | N20 100RPM motor (3V-6V) | 6 | One per wheel, 3.1mm D-shaft |
| 2 | SG90 micro servo | 4 | Steering (FL, FR, RL, RR) |
| 3 | L298N dual H-bridge | 2 | Motor drivers (3 motors per driver via parallel pairs) |

---

## Assembly Hierarchy

```
Rover
├── Differential Bar (300mm 8mm rod)
│   ├── DiffAdapter_L (press-fit, bearing)
│   ├── DiffAdapter_C (press-fit, bearing, body mount)
│   └── DiffAdapter_R (press-fit, bearing)
│
├── Suspension_Left
│   ├── Rocker Hub Connector (bearing on diff bar)
│   │   ├── Rocker Front Tube (165mm)
│   │   │   └── Front Wheel Connector
│   │   │       ├── Steering Bracket FL (608ZZ bearing)
│   │   │       │   ├── N20 Motor FL
│   │   │       │   └── Wheel FL (V2, Perseverance-style)
│   │   │       └── Servo Mount FL (SG90)
│   │   │
│   │   └── Rocker Rear Tube (75mm)
│   │       └── Bogie Pivot Connector (608ZZ bearing)
│   │           ├── Bogie Front Tube (75mm)
│   │           │   └── Middle Wheel Connector
│   │           │       ├── Fixed Wheel Mount ML
│   │           │       │   ├── N20 Motor ML
│   │           │       │   └── Wheel ML
│   │           │
│   │           └── Bogie Rear Tube (75mm)
│   │               └── Rear Wheel Connector
│   │                   ├── Steering Bracket RL
│   │                   │   ├── N20 Motor RL
│   │                   │   └── Wheel RL
│   │                   └── Servo Mount RL (SG90)
│
└── Suspension_Right (mirror of left)
```

---

## New Connector Parts to Design

These 5 connector types need CAD scripts written. They replace the monolithic rocker/bogie arms.

### 1. Rocker Hub Connector
```
        ┌──────┐
  ══════╪  HUB ╪══════    ← 8mm tube sockets (front + rear)
        │ ◯608 │           ← 608ZZ bearing for diff bar pivot
        └──┬───┘
           │
        DiffBar
```
- Size: ~40×35×30mm
- Features: 2× tube sockets (front + rear), 1× 608ZZ bearing seat, 1× 8mm diff bar bore
- This is the most complex connector

### 2. Bogie Pivot Connector
```
  ══════╪  PIVOT ╪══════   ← 8mm tube sockets (×3: rocker-rear + bogie-front + bogie-rear)
        │  ◯608  │          ← 608ZZ bearing for pivot axis
        └────────┘
```
- Size: ~45×35×25mm
- Features: 3× tube sockets, 1× 608ZZ bearing seat
- The rocker tube enters from the top, bogie tubes go front+rear

### 3. Front/Rear Wheel Connector
```
  ══════╪ END ╪
        │     │──── Steering bracket mount (M3 heat-set × 2)
        │     │──── Servo mount tab
        └─────┘
```
- Size: ~30×25×25mm
- Features: 1× tube socket, flat face for steering bracket, servo mount tab

### 4. Middle Wheel Connector
```
  ══════╪ END ╪
        │     │──── Fixed mount interface (M3 heat-set × 2)
        └─────┘
```
- Size: ~25×25×20mm
- Features: 1× tube socket, flat face for fixed wheel mount

---

## Comparison: Old vs New Approach

| Aspect | Old (Monolithic Arms) | New (Tube + Connector) |
|---|---|---|
| Parts to print | 6 arms (2 rocker front, 2 rear, 2 bogie) | 10 connectors (5 types × 2 sides) |
| Print time | ~25 hrs (6 long arms) | ~12 hrs (10 small connectors) |
| Structural strength | PLA only (weak in bending) | Steel tube (excellent) |
| Total weight | ~180g (PLA arms) | ~120g (connectors) + ~150g (steel) = ~270g |
| Failure mode | Brittle snap at layer lines | Connector crush (graceful) |
| Adjustability | None | Cut tubes to length |
| Aesthetics | Blocky | NASA/industrial look |
| Complexity | Simple (one print) | More parts, more assembly |

**Verdict:** The tube + connector approach is better for a rover that needs to drive outdoors. The trade-off is slightly more weight and assembly complexity, but much better strength and a great look.

---

## Print Schedule (Suspension Only)

| Priority | Part | Qty | Est. Time | Est. PLA |
|---|---|-----|---|---|
| 1 | Bearing Test Piece | 1 | 1h | 5g |
| 2 | Calibration Test Card | 1 | 0.5h | 3g |
| 3 | Wheel V2 | 6 | 24h (4h each) | 120g |
| 4 | Rocker Hub Connector | 2 | 4h (2h each) | 30g |
| 5 | Bogie Pivot Connector | 2 | 4h | 30g |
| 6 | Front Wheel Connector | 2 | 2h | 16g |
| 7 | Rear Wheel Connector | 2 | 2h | 16g |
| 8 | Middle Wheel Connector | 2 | 1.5h | 10g |
| 9 | Steering Bracket | 4 | 18h (4.5h each) | 104g |
| 10 | Servo Mount | 4 | 6h (1.5h each) | 32g |
| 11 | Fixed Wheel Mount | 2 | 2h | 12g |
| 12 | Diff Bar Adapter | 3 | 3h | 20g |
| **Total** | | **31** | **~68h** | **~398g** |

---

## Next Steps

1. **Review this parts list together** — decide on tube material (steel vs aluminium)
2. **Design the 5 new connector types** — CAD scripts needed
3. **Run wheel V2 in Fusion 360** — evaluate aesthetics, iterate spoke curve
4. **Run suspension assembly** — see all parts together
5. **Drop reference screenshots** into `cad/reference/suspension-refs/` for design inspiration
6. **Order hardware** — 608ZZ bearings, 1m × 8mm steel rod, M3 fastener kit, heat-set inserts

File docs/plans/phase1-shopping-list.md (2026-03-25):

# Phase 1 Shopping List

**Budget**: ~£80 (EA-06 estimates $102 / ~£80 at current rates)
**Purpose**: 0.4 scale prototype — basic driving and steering validation
**Date**: 2026-03-15

---

## Electronics

### 1. Microcontroller

| Item | Qty | Approx Price | Where to Buy | Notes |
|---|-----|---|---|---|
| ESP32-S3 DevKitC-1 N16R8 (USB-C) | 1 | £7 | [AliExpress](https://www.aliexpress.com/w/wholesale-esp32-s3-devkitc-1-n16r8.html) / [Amazon UK](https://www.amazon.co.uk/s?k=esp32-s3+devkitc) | 16MB flash, 8MB PSRAM. Get the official Espressif layout or YD-ESP32-S3 clone. Must be N16R8 variant for Phase 2 PSRAM needs. Amazon ~£12 but faster delivery. |

### 2. Motor Drivers

| Item | Qty | Approx Price | Where to Buy | Notes |
|---|-----|---|---|---|
| L298N Dual H-Bridge Motor Driver Module | 2 | £2.50 each (£5) | [Amazon UK](https://www.amazon.co.uk/s?k=L298N+motor+driver) / [The Pi Hut](https://thepihut.com) | Each board drives 2 motor channels. W2+W3 wired in parallel on L298N #1 channel B; W5+W4 in parallel on #2 channel B. Onboard 5V regulator powers ESP32 + servos. |

### 3. Motors

| Item | Qty | Approx Price | Where to Buy | Notes |
|---|-----|---|---|---|
| GA12-N20 DC Gearmotor 6V 100RPM with Hall Encoder | 6 | £2.50 each (£15) | [AliExpress](https://www.aliexpress.com/w/wholesale-n20-gear-motor-encoder-100rpm-6v.html) / [Amazon UK](https://www.amazon.co.uk/s?k=N20+gear+motor+encoder+100rpm) | **IMPORTANT: Confirm GA12-N20, 1:100 gear ratio, metal gearbox, 3mm D-shaft**. Rated torque ~2 kg·cm, stall ~10-16 kg·cm. Plastic gearbox versions strip under load — insist on metal. 12×10×24mm body (15mm can + 9mm gearbox), ~10g. AliExpress ~£1.50 each (2-4 week shipping). Amazon ~£3-4 each. |

### 4. Servos

| Item | Qty | Approx Price | Where to Buy | Notes |
|---|-----|---|---|---|
| SG90 Micro Servo 9g | 4 | £1.50 each (£6) | [Amazon UK](https://www.amazon.co.uk/s?k=SG90+micro+servo) / [The Pi Hut](https://thepihut.com/products/tower-pro-sg90-digital-9g-micro-servo) | 1.8 kg-cm at 4.8V, sufficient for 1 kg prototype steering. Comes with mounting screws and horn set. MG90S (metal gear, ~£3 each) is a worthy upgrade if budget allows — more durable. |

### 5. Sensors (Optional for Phase 1)

| Item | Qty | Approx Price | Where to Buy | Notes |
|---|-----|---|---|---|
| BNO055 IMU Breakout (9-DOF) | 1 | £12 | [Pimoroni](https://shop.pimoroni.com) / [Amazon UK](https://www.amazon.co.uk/s?k=BNO055+breakout) | Optional for Phase 1 — useful for tilt/orientation testing but not required for basic driving. Defer to Phase 2 if budget-tight. I2C address 0x28. |
| HC-SR04 Ultrasonic Sensor | 2 | £1.50 each (£3) | [Amazon UK](https://www.amazon.co.uk/s?k=HC-SR04+ultrasonic) / [CPC Farnell](https://cpc.farnell.com) | Optional — 2 front-facing for basic obstacle detection. Defer to Phase 2 if budget-tight. |

### 6. Power

| Item | Qty | Approx Price | Where to Buy | Notes |
|---|-----|---|---|---|
| 2S LiPo 7.4V 2200mAh (XT60) | 1 | £10 | [Amazon UK](https://www.amazon.co.uk/s?k=2S+LiPo+2200mAh) / [HobbyKing UK](https://hobbyking.com) | 30C+ discharge rating. Check connector matches your charger. XT60 standard throughout. Gives ~45 min runtime at 3A draw. |
| 2S/3S LiPo Balance Charger | 1 | £8 | [Amazon UK](https://www.amazon.co.uk/s?k=2S+LiPo+balance+charger) | IMAX B6 mini clone or similar. Essential safety item — never charge LiPo without a balance charger. If you already own one, skip this. |
| LiPo Safe Bag | 1 | £4 | [Amazon UK](https://www.amazon.co.uk/s?k=lipo+safe+bag) | Fireproof charging/storage bag. Non-negotiable safety item for LiPo use. |

### 7. Safety

| Item | Qty | Approx Price | Where to Buy | Notes |
|---|-----|---|---|---|
| Mini Toggle Switch (SPST, panel mount) | 1 | £1 | [Amazon UK](https://www.amazon.co.uk/s?k=mini+toggle+switch+panel+mount) / [CPC Farnell](https://cpc.farnell.com) | Main power switch. 15mm panel mount hole in rear body wall. Rated for 5A+ at 12V. |
| Inline Blade Fuse Holder + 5A Fuse | 1 | £2 | [Amazon UK](https://www.amazon.co.uk/s?k=inline+blade+fuse+holder) | Between battery and L298N power rail. Protects against short circuits. |
| E-Stop Tactile Button (momentary, NC, panel mount) | 1 | £1 | [Amazon UK](https://www.amazon.co.uk/s?k=momentary+push+button+panel+mount+normally+closed) / [CPC Farnell](https://cpc.farnell.com) | Emergency stop — normally-closed momentary button. Press to cut motor power. Wired in series with motor power rail. Panel mount in body wall. See EA-15 safety systems. |
| Green LED (3mm or 5mm) + 330 ohm Resistor | 1 | £0.50 | [Amazon UK](https://www.amazon.co.uk/s?k=green+LED+5mm) / [CPC Farnell](https://cpc.farnell.com) | Power indicator — lights when main switch is on. Mount in body wall near switch. 330 ohm resistor (WS2812B data line series resistor). See EA-15. |

### 8. Servo Power

| Item | Qty | Approx Price | Where to Buy | Notes |
|---|-----|---|---|---|
| 5V 3A Buck Converter (XL4015 or similar) | 1 | £3 | [Amazon UK](https://www.amazon.co.uk/s?k=5V+3A+buck+converter+XL4015) / [AliExpress](https://www.aliexpress.com/w/wholesale-5V+3A+buck+converter.html) | **CRITICAL**: Dedicated 5V servo power supply. Replaces L298N onboard 5V regulator which cannot supply 4 servos + ESP32 reliably under load. Input 7-35V from battery, output 5V 3A. Wired to servo power rail only. See EA-19 wiring diagram. |

---

## Mechanical

### 1. Bearings

| Item | Qty | Approx Price | Where to Buy | Notes |
|---|-----|---|---|---|
| 608ZZ Bearings (8x22x7mm) | 12 | £0.40 each (£5) | [Amazon UK](https://www.amazon.co.uk/s?k=608ZZ+bearings) | Phase 1 needs 9: 2 rocker pivots, 2 bogie pivots, 1 diff pivot, 4 steering pivots (EA-25/EA-26). Buy 12 for spares. Same as skateboard bearings — buy a 10-pack + 2 singles, or a 20-pack for Phase 2 stock. |

### 2. Fasteners

| Item | Qty | Approx Price | Where to Buy | Notes |
|---|-----|---|---|---|
| M3 Heat-Set Inserts (OD 5.7mm, L 4.6mm, brass) | 50 pack | £4 | [Amazon UK](https://www.amazon.co.uk/s?k=M3+heat+set+inserts+brass) / [CNC Kitchen style from AliExpress](https://www.aliexpress.com/w/wholesale-m3-heat-set-insert.html) | CNC Kitchen / Ruthex style knurled brass. Hole prints at 4.8mm; insert melts into plastic. Need ~40 for Phase 1 body + brackets (more with 4-segment body). Get 100-pack (£6) if planning ahead for Phase 2. **PLA insert temp: ~170-180C** (lower than PETG's 200-220C) — go slow to avoid melting surrounding plastic. |
| M3 Socket Cap Screw Assortment (6/8/10/12/16/20mm) | 1 set | £5 | [Amazon UK](https://www.amazon.co.uk/s?k=M3+socket+cap+screw+assortment) | Need ~50 screws in various lengths. A 300-piece assortment box covers Phase 1 and Phase 2. |
| M3 Nut + Washer Assortment | 1 set | £3 | [Amazon UK](https://www.amazon.co.uk/s?k=M3+nut+washer+assortment) | Often bundled with screw kits. Need ~30 nuts, ~30 washers. |
| M8 x 40mm Hex Bolt | 4 | £2 | [Amazon UK](https://www.amazon.co.uk/s?k=M8+hex+bolt+40mm) / Local hardware store | Rocker + bogie pivot shafts. Stainless preferred. |
| M8 x 30mm Hex Bolt | 4 | £2 | [Amazon UK](https://www.amazon.co.uk/s?k=M8+hex+bolt+30mm) | Steering pivot shafts. |
| M8 Nyloc Nuts | 8 | £1.50 | [Amazon UK](https://www.amazon.co.uk/s?k=M8+nyloc+nut) | Lock nuts for all M8 pivots — prevents loosening under vibration. |
| M8 Washers | 16 | £1.50 | [Amazon UK](https://www.amazon.co.uk/s?k=M8+washer+stainless) | 2 per pivot (both sides of each bearing). |
| M2 x 8mm Screws | 8 | £1 | [Amazon UK](https://www.amazon.co.uk/s?k=M2+screw+assortment) | SG90 servo mounting (4 servos x 2 screws). Often included with servo packaging. |
| M2 × 4mm Grub/Set Screws (hex socket) | 6 | £2 | [Amazon UK](https://www.amazon.co.uk/s?k=M2+grub+set+screw+4mm) / [CPC Farnell](https://cpc.farnell.com) | Wheel hub shaft retention — tighten against D-flat on N20 3mm shaft to prevent wheels slipping. 1 per wheel. Buy a few spares. See wheel CAD script. |
| M2 × 10mm Socket Cap Screws | 8 | £1 | [Amazon UK](https://www.amazon.co.uk/s?k=M2+socket+cap+screw+10mm) | Steering horn link pin joints — 2 per link × 4 links. Stainless preferred. EA-27. |
| M2 Nyloc Nuts | 8 | £1 | [Amazon UK](https://www.amazon.co.uk/s?k=M2+nyloc+nut) | Horn link pin retention — self-locking, essential for vibration. EA-27. |
| M2 Nylon Flat Washers | 16 | £1 | [Amazon UK](https://www.amazon.co.uk/s?k=M2+nylon+washer) | Horn link pin joints — 2 per pin, smooth rotation on PLA. EA-27. |
| 3mm × 20mm Steel Dowel Pins | 4 | £2 | [Amazon UK](https://www.amazon.co.uk/s?k=3mm+steel+dowel+pin+20mm) / [RS Components](https://uk.rs-online.com) | Body quadrant alignment — press-fit into matching 3.0mm holes at quadrant seams. Prevents lateral shift when bolting quadrants together. See EA-08 body design. |

### 3. Shafts

| Item | Qty | Approx Price | Where to Buy | Notes |
|---|-----|---|---|---|
| 8mm Steel Rod, 1m length | 2 | £3 each (£6) | [Amazon UK](https://www.amazon.co.uk/s?k=8mm+steel+rod+1m) / Local hardware store / [RS Components](https://uk.rs-online.com) | Cut to lengths: 1× 400mm (diff bar, EA-26), 2× 150mm (rocker front tubes), 6× 60mm (2 rocker rear + 2 bogie front + 2 bogie rear). 8mm fits 608ZZ bearing inner race. Silver steel or mild steel both fine. Total ~1060mm — needs 2× 1m rods. |
| 8mm Shaft Collars (bore 8mm) | 4 | £3 | [Amazon UK](https://www.amazon.co.uk/s?k=8mm+shaft+collar) | Retain diff bar ends + rocker pivot shafts. Alternatively use printed adapters with M3 grub screws. |
| M3 Rod-End Bearings (Heim joints) | 4 | £3 | [Amazon UK](https://www.amazon.co.uk/s?k=M3+rod+end+bearing+heim+joint) / [AliExpress](https://www.aliexpress.com/w/wholesale-M3+rod+end+bearing.html) | For differential links — ball joints at each end of each link (2 links × 2 ends). Allow angular misalignment between diff bar (X-axis) and rocker (Y-axis). See EA-26 Section 9. |
| M3 x 20mm Bolts (for diff links) | 4 | £1 | Included in M3 assortment | Through-bolts for attaching rod-end bearings to diff link bar ends. |

---

## 3D Printing

**Printer**: CTC 3D Bizer (225×145mm bed) — PLA only (no PETG or TPU capability).

> **Body segmentation**: The CTC Bizer's 225×145mm bed requires the rover body (440×260mm at 0.4 scale) to be split into **4 quadrants** to fit the build plate. All quadrants are ~220×130mm (Y_SPLIT=0, pivot boss trimmed to bounds). This adds ~4 joining surfaces, increasing total filament usage by ~50g and requiring ~24 additional heat-set inserts for segment-to-segment bolting.

| Item | Qty | Approx Price | Where to Buy | Notes |
|---|-----|---|---|---|
| PLA Filament 1.75mm, 1kg spool | 2 | £14 each (£28) | [Amazon UK](https://www.amazon.co.uk/s?k=PLA+filament+1kg) | Recommended brand: eSUN PLA+ or Sunlu PLA — both print well and are widely available on Amazon UK. Total print weight ~850g + 280g waste/failures = ~1130g (extra joining surfaces from 4-segment body). Two spools gives comfortable margin. Colour: grey or black (mars rover aesthetic). |

> **Wheel traction (preferred)**: Separate **TPU 95A tires** (rover_tire.py) press-fit onto PLA rims. Requires a friend's TPU-capable printer or online printing service. 86mm OD × 70mm bore × 32mm wide, 48 tread ribs. ~10g each.
>
> **Wheel traction (fallback)**: If no TPU printer available, set `USE_TPU_TIRE=False` in rover_wheel.py to enable O-ring groove mode. Use **rubber O-rings** (70mm ID × 3mm cross-section) in wheel rim grooves. Buy a bag of 20+ (~£3).

| Item | Qty | Approx Price | Where to Buy | Notes |
|---|-----|---|---|---|
| TPU 95A Filament 250g (optional) | 1 | £8 | [Amazon UK](https://www.amazon.co.uk/s?k=TPU+95A+filament) | For 6 tires on a friend's TPU-capable printer. 60g needed + margin. |
| O-Rings 70mm ID × 3mm (fallback) | 20 | £3 | [Amazon UK](https://www.amazon.co.uk/s?k=70mm+ID+3mm+O-ring) | Only needed if NOT using TPU tires. 18 needed (3 per wheel × 6) + spares. |

---

## Wiring & Connectors

| Item | Qty | Approx Price | Where to Buy | Notes |
|---|-----|---|---|---|
| 22AWG Silicone Wire (6 colours, 5m each) | 1 set | £6 | [Amazon UK](https://www.amazon.co.uk/s?k=22AWG+silicone+wire+set) | Signal wires for motors, servos, encoders. Silicone is flexible and heat-resistant. |
| 18AWG Silicone Wire (red + black, 3m each) | 1 set | £4 | [Amazon UK](https://www.amazon.co.uk/s?k=18AWG+silicone+wire) | Power wires from battery to L298N boards. |
| JST-XH Connector Kit (2.54mm pitch) | 1 kit | £6 | [Amazon UK](https://www.amazon.co.uk/s?k=JST+XH+connector+kit) | For making neat motor/servo connections. Includes 2/3/4/5-pin housings + crimps. |
| Dupont Connector Kit (2.54mm) | 1 kit | £5 | [Amazon UK](https://www.amazon.co.uk/s?k=dupont+connector+kit) | For breadboard jumper wires and ESP32 header connections. Male + female pins + housings. |
| XT60 Connectors (male + female pair) | 2 pairs | £2 | [Amazon UK](https://www.amazon.co.uk/s?k=XT60+connector) | Battery to power switch connection. Match your LiPo connector type. |
| Half-Size Breadboard (400 tie points) | 1 | £3 | [Amazon UK](https://www.amazon.co.uk/s?k=half+size+breadboard) / [Pimoroni](https://shop.pimoroni.com) | For prototyping servo/encoder connections before soldering. |
| Heat Shrink Tubing Assortment | 1 kit | £3 | [Amazon UK](https://www.amazon.co.uk/s?k=heat+shrink+tubing+assortment) | Various diameters (1.5-10mm). Essential for insulating solder joints. |
| Voltage Divider Resistors: 10k + 4.7k (1/4W) | 2 each | £0.50 | [Amazon UK](https://www.amazon.co.uk/s?k=resistor+assortment) / [CPC Farnell](https://cpc.farnell.com) | For battery voltage monitoring on GPIO14. Buy a resistor assortment kit if you don't have one. |

---

## Consumables & Sundries

| Item | Qty | Approx Price | Where to Buy | Notes |
|---|-----|---|---|---|
| 100nF Ceramic Capacitors (104) | 6+ | £1 | [Amazon UK](https://www.amazon.co.uk/s?k=100nF+ceramic+capacitor) / [CPC Farnell](https://cpc.farnell.com) | Motor terminal noise suppression — solder one across each motor's ±terminals. Buy a pack of 20-50 (cheap). Referenced in CLAUDE.md conventions and EA-19. |
| Small Zip Ties (100mm) | 1 bag (100) | £2 | [Amazon UK](https://www.amazon.co.uk/s?k=100mm+zip+ties) | Wire bundle management at strain relief points, securing motor wires to suspension arms. Referenced in EA-17, EA-19. |
| Velcro Cable Ties (reusable) | 1 pack (20) | £3 | [Amazon UK](https://www.amazon.co.uk/s?k=velcro+cable+ties) | Reusable wire management inside body, battery retention strap. Referenced in EA-08, EA-14. |
| Hot Glue Sticks (7mm, clear) | 1 pack (20) | £2 | [Amazon UK](https://www.amazon.co.uk/s?k=hot+glue+sticks+7mm) | Strain relief at solder joints, securing connectors, temporary fixturing. Referenced in EA-19. Requires hot glue gun. |

---

## Tools (if not already owned)

| Item | Qty | Approx Price | Where to Buy | Notes |
|---|-----|---|---|---|
| Soldering Iron (temperature controlled) | 1 | £25-40 | [Amazon UK](https://www.amazon.co.uk/s?k=soldering+iron+temperature+controlled) | If you don't have one. Pinecil or TS100 are excellent portable options. Need pointed tip for wiring + conical tip for heat-set inserts. |
| Heat-Set Insert Tip (for soldering iron) | 1 | £5 | [Amazon UK](https://www.amazon.co.uk/s?k=heat+set+insert+tip+soldering+iron) / [CNC Kitchen](https://cnckitchen.store) | M3 size. Fits most soldering irons with standard tips. Makes inserting brass inserts clean and straight. |
| Wire Stripper / Crimper | 1 | £8 | [Amazon UK](https://www.amazon.co.uk/s?k=wire+stripper+crimper) | Self-adjusting type recommended. Essential for JST/Dupont crimping. |
| Multimeter | 1 | £10-15 | [Amazon UK](https://www.amazon.co.uk/s?k=digital+multimeter) | If you don't have one. Needed for voltage checks, continuity testing. |
| Hex Key Set (1.5, 2, 2.5, 4, 5mm) | 1 set | £3 | [Amazon UK](https://www.amazon.co.uk/s?k=hex+key+set+metric) | 2mm for M3 socket caps, 5mm for M8 hex bolts. |
| SD Card 8GB (or larger) | 1 | £4 | [Amazon UK](https://www.amazon.co.uk/s?k=sd+card+8gb) | For CTC Bizer printer — load x3g files via SD card. Not a rover component but essential for print workflow. Any speed class works. |
| USB-C Cable (data + power, 1m+) | 1 | £3 | [Amazon UK](https://www.amazon.co.uk/s?k=USB-C+data+cable) | ESP32-S3 programming and serial debug. Must be a data cable (not charge-only). 1-2m length for comfortable bench work. |

---

## Total Estimated Cost

### Core Components (required)

| Category | Estimated Cost |
|---|---|
| Microcontroller (ESP32-S3) | £7 |
| Motor drivers (2x L298N) | £5 |
| Motors (6x N20 w/ encoder) | £15 |
| Servos (4x SG90) | £6 |
| Power (2S LiPo + charger + safe bag) | £22 |
| Servo power (5V 3A buck converter) | £3 |
| Safety (switch + fuse + E-stop + LED) | £4.50 |
| Bearings (12x 608ZZ) | £5 |
| Fasteners (M3 set + M8 + M2 grub screws + dowel pins + heat-set inserts) | £24 |
| Shafts (8mm rod + collars) | £4 |
| Filament (2x 1kg PLA) | £28 |
| Wiring & connectors | £30 |
| **Core Total** | **~£153** |

### Consumables & Sundries

| Category | Estimated Cost |
|---|---|
| 100nF ceramic capacitors | £1 |
| Zip ties (100mm bag) | £2 |
| Velcro cable ties | £3 |
| Hot glue sticks | £2 |
| Rubber O-rings 70mm ID × 3mm (wheel traction fallback) | £3 |
| Glue stick (bed adhesion for CTC Bizer) | £2 |
| **Consumables Total** | **~£13** |

### Optional Phase 1 Items

| Category | Estimated Cost |
|---|---|
| BNO055 IMU | £12 |
| HC-SR04 ultrasonic (x2) | £3 |
| **Optional Total** | **~£15** |

### Tools (if needed)

| Category | Estimated Cost |
|---|---|
| Soldering iron | £30 |
| Heat-set insert tip | £5 |
| Wire stripper/crimper | £8 |
| Multimeter | £12 |
| Hex key set | £3 |
| SD card 8GB (CTC Bizer) | £4 |
| USB-C cable (ESP32 programming) | £3 |
| **Tools Total** | **~£65** |

### Budget Summary

| | Cost |
|---|---|
| Core components | ~£153 |
| Consumables & sundries | ~£13 |
| Optional sensors | ~£15 |
| Tools (if needed) | ~£65 |
| **Grand Total (everything)** | **~£246** |
| **Grand Total (core + consumables, have tools)** | **~£166** |

> **Note**: The EA-06 estimate of $102/~£80 assumes AliExpress pricing for most components with 2-4 week shipping and only 1x 500g filament spool. The figures above use Amazon UK pricing (typically 1.5-2x AliExpress) and 2x 1kg PLA spools for realistic print margin. To hit the EA-06 budget, order motors, ESP32, servos, drivers, heat-set inserts, and connectors from AliExpress (~£50 saving) and accept the longer delivery time.

---

## Recommended Buy Order

### Order 1: Filament (buy now, start printing while waiting for electronics)

| Item | Cost | Why First |
|---|---|---|
| 2x PLA filament (1kg) | £28 | ~65 hours of printing ahead. Start with bearing test piece, then wheels, then structural parts. Body needs 4 quadrants to fit CTC Bizer's 225×145mm bed — start printing early. Printing can happen in parallel with electronics shipping. |

### Order 2: Electronics (buy next — AliExpress for budget, Amazon for speed)

| Item | Source | Cost |
|---|---|---|
| ESP32-S3 DevKitC-1 N16R8 | AliExpress (£7) or Amazon (£12) | £7-12 |
| 6x N20 100RPM motors w/ encoder | AliExpress (£10) or Amazon (£18) | £10-18 |
| 4x SG90 servos | AliExpress (£4) or Amazon (£6) | £4-6 |
| 2x L298N motor drivers | AliExpress (£3) or Amazon (£5) | £3-5 |
| Breadboard | Amazon | £3 |
| Dupont connector kit | Amazon | £5 |
| Wire (22AWG + 18AWG) | Amazon | £10 |

**Why second**: You need the ESP32 and motors in hand to bench-test before final assembly. Order from AliExpress early to overlap with print time.

### Order 3: Mechanical Hardware (buy once CAD is finalised and first prints are done)

| Item | Source | Cost |
|---|---|---|
| 12x 608ZZ bearings | Amazon | £5 |
| M3 fastener set + heat-set inserts | Amazon | £12 |
| M8 bolts, nyloc nuts, washers | Amazon / hardware store | £7 |
| M2 × 4mm grub screws (×6) + 3mm dowel pins (×4) | Amazon | £4 |
| 8mm steel rod + shaft collars | Amazon / hardware store | £4 |

**Why third**: You need actual printed parts in hand to verify bearing press-fit dimensions and bolt lengths before committing to quantities.

### Order 4: Power (buy last — only when ready for powered testing)

| Item | Source | Cost |
|---|---|---|
| 2S LiPo 2200mAh | Amazon | £10 |
| LiPo balance charger | Amazon | £8 |
| LiPo safe bag | Amazon | £4 |
| Power switch + fuse holder + E-stop button | Amazon | £4 |
| Green LED + 330 ohm resistor | Amazon | £0.50 |
| 5V 3A buck converter (servo BEC) | Amazon / AliExpress | £3 |
| XT60 connectors | Amazon | £2 |
| JST-XH connector kit | Amazon | £6 |
| Heat shrink tubing | Amazon | £3 |
| Resistors (voltage divider) | Amazon | £0.50 |

**Why last**: No point having a LiPo sitting around while printing and assembling. It only becomes relevant once the chassis is built and electronics are wired. Bench testing can use a USB power bank or lab supply.

---

## Bench Testing Checklist (before full assembly)

Once Order 2 arrives, test these on the breadboard before building into the chassis:

- [ ] ESP32-S3 powers on via USB, uploads firmware (Arduino IDE / PlatformIO)
- [ ] L298N drives a single N20 motor forward/reverse via ESP32 PWM
- [ ] SG90 servo sweeps 0-180 degrees via ESP32 LEDC
- [ ] Encoder pulses read correctly on ESP32 GPIO interrupt
- [ ] 5V buck converter outputs stable 5V under servo load (check with multimeter)
- [ ] All 6 motors spin (test each individually)
- [ ] E-stop button cuts motor power when pressed, restores when released
- [ ] Battery voltage divider reads correctly on GPIO14 ADC
- [ ] Green power LED illuminates when main switch is on

---

*Phase 1 Shopping List v1.0 — 2026-03-15*

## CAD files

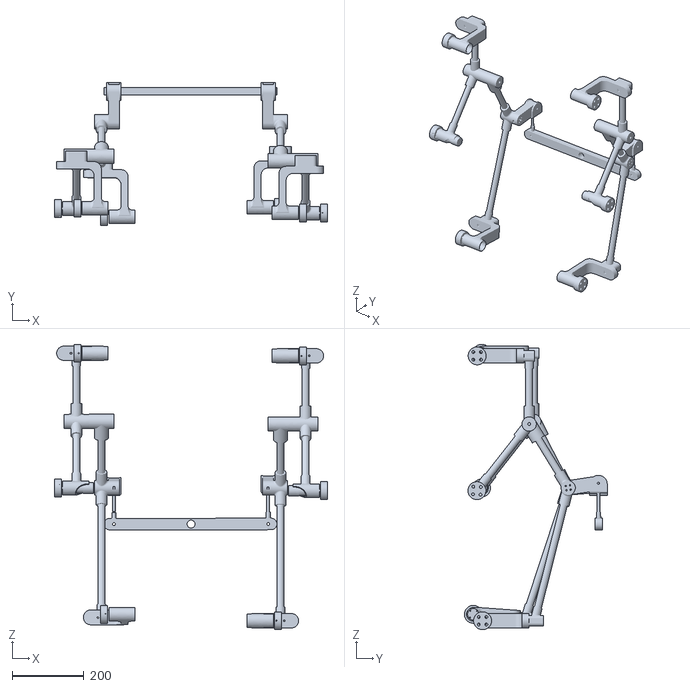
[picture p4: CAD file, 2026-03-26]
cad/reference-suspension/checkpoints/suspension_clean_fullscale.stl
761.0 x 399.3 x 795.6

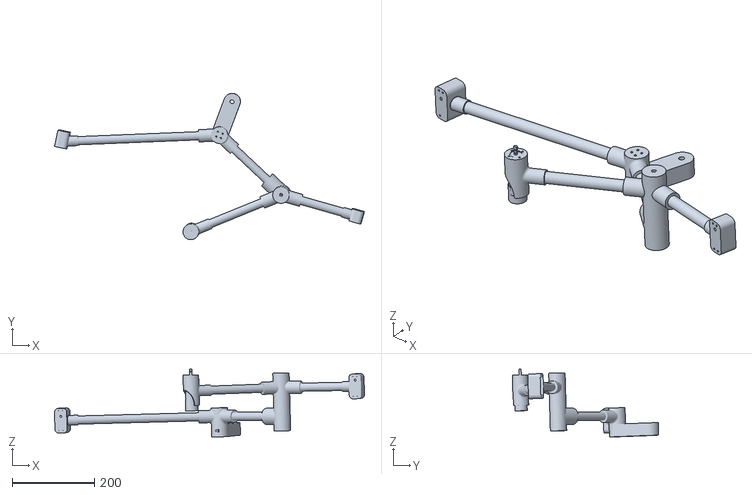
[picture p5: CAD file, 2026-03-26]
cad/reference-suspension/extracted/rb_full_assembly.stl
751.7 x 355.2 x 164.7

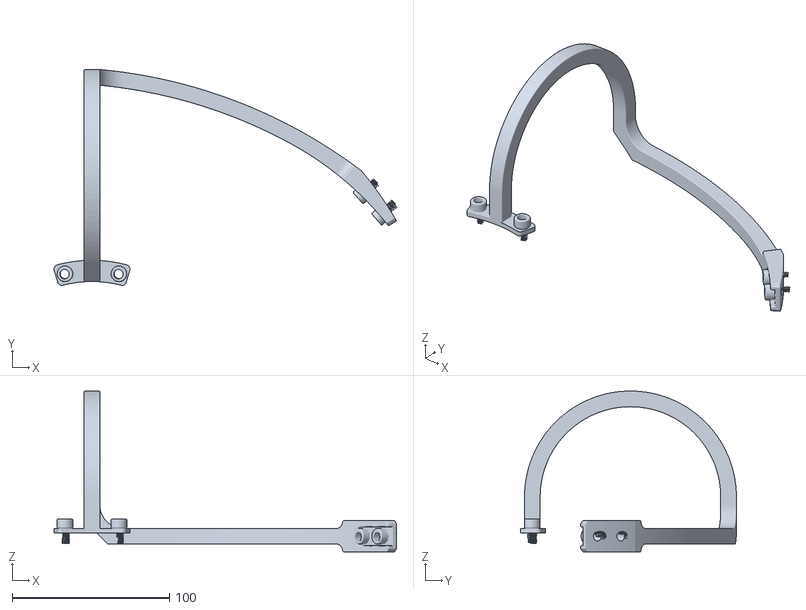
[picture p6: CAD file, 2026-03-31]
cad/reference-wheels/components/Spoke_1_fullscale.stl
218.5 x 137.5 x 102.5

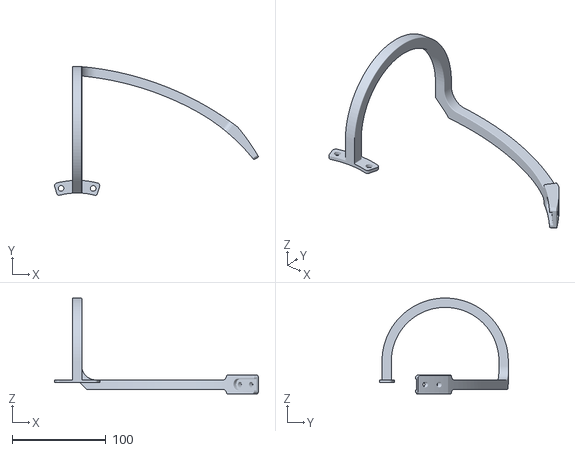
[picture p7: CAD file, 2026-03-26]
cad/reference-wheels/curiosity_spoke6_fullscale.stl
218.0 x 137.5 x 102.5

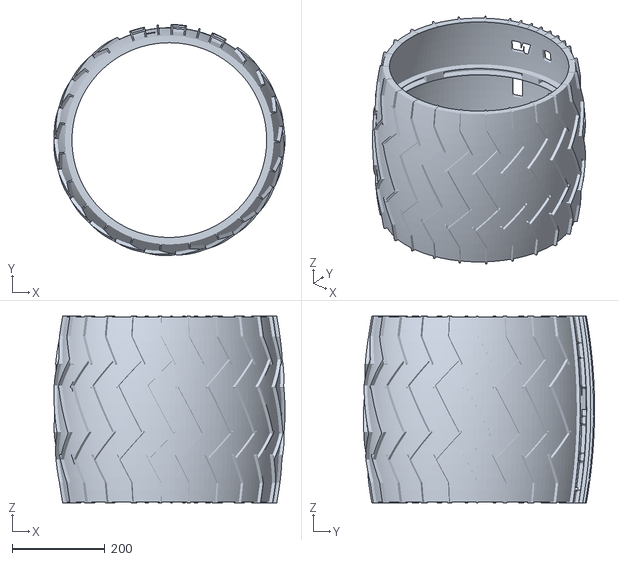
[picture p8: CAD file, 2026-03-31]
cad/reference-wheels/components/Tread_1_fullscale.stl
499.2 x 499.6 x 404.0

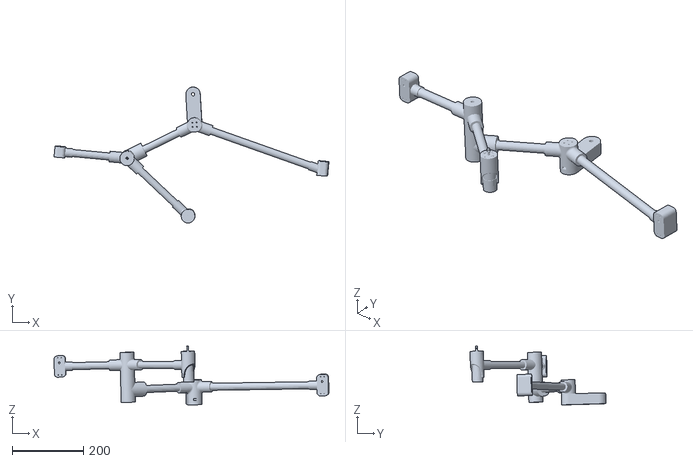
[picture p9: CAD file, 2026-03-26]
cad/reference-suspension/extracted/rb3_full_assembly.stl
772.8 x 382.4 x 165.4

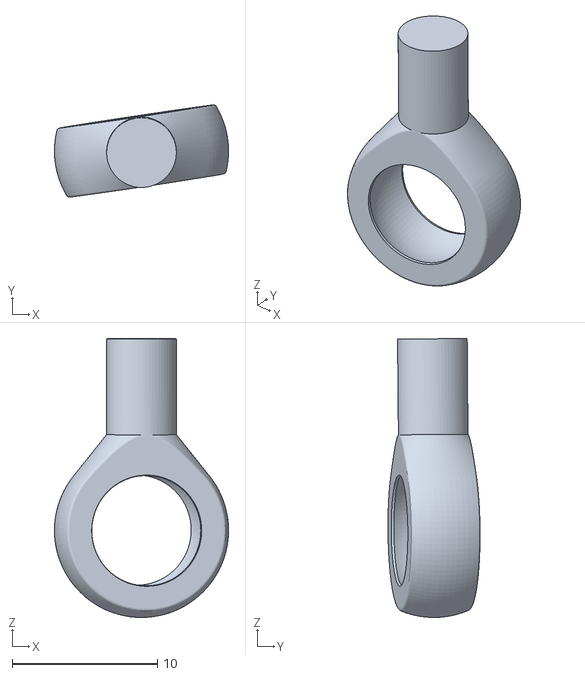
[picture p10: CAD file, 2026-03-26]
cad/reference-suspension/extracted/0.4-scale/individual/Rod_End_M8_1_main_M8_1_04x.stl
12.0 x 6.35 x 19.2

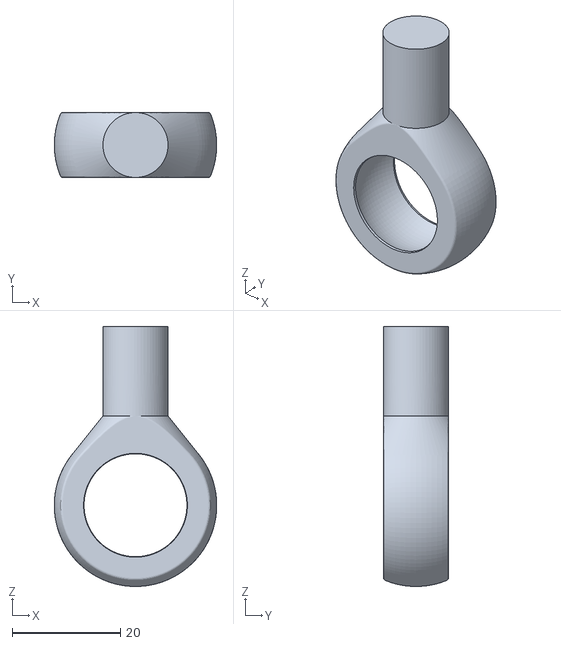
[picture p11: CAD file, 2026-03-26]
cad/reference-suspension/extracted/full-scale/individual/Rod_End_M8_1_1_main_M8_2.stl
30.0 x 12.0 x 48.0

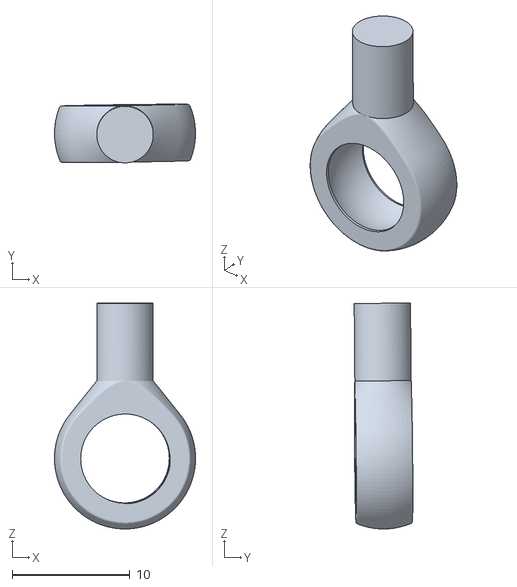
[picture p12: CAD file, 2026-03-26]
cad/reference-suspension/extracted/0.4-scale/individual/Rod_End_M8_1_1_main_M8_2_04x.stl
12.0 x 4.99 x 19.2

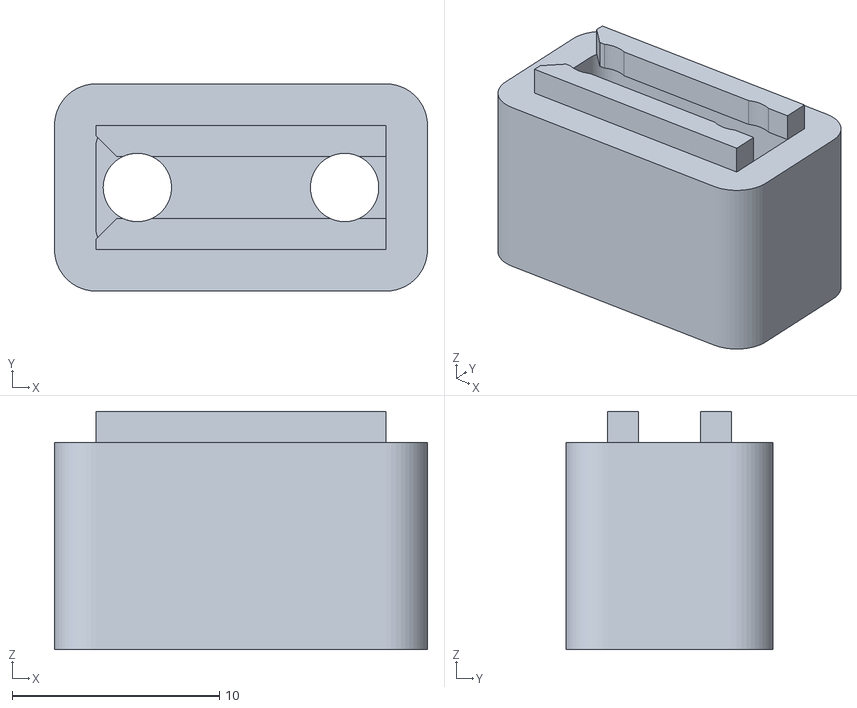
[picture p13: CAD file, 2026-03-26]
3d-print/body/StrainReliefClip.stl
18.0 x 10.0 x 11.5

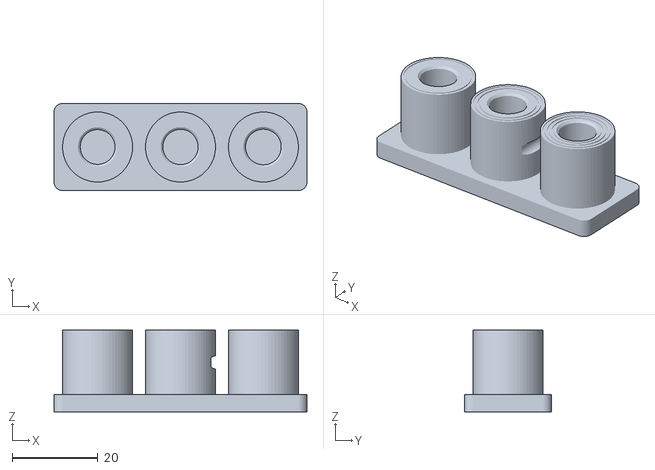
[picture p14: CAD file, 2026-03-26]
3d-print/calibration/TubeSocketTest.stl
58.9 x 20.3 x 19.0

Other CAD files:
cad/reference-wheels/curiosity_tread_fullscale.stl
3d-print/body/BatteryTray.stl
3d-print/body/BodyQuadrant.stl
3d-print/body/ElectronicsTray.stl
3d-print/body/FuseHolderBracket.stl
3d-print/body/SwitchMount.stl
3d-print/body/TopDeck.stl
3d-print/calibration/BearingTestPiece.stl
3d-print/calibration/CalibrationTestCard.stl
3d-print/drivetrain/FixedWheelMount.stl
3d-print/hardware/608ZZ_Bearing.stl
3d-print/hardware/8mm_AxleStub.stl
3d-print/hardware/M3x10_ButtonHead.stl
3d-print/steering/ServoMount.stl
3d-print/steering/SteeringBracket.stl
3d-print/steering/SteeringHornLink.stl
3d-print/steering/SteeringKnuckle.stl
3d-print/suspension/BogiePivotConnector.stl
3d-print/suspension/CableClip.stl
3d-print/suspension/DifferentialLink.stl
3d-print/suspension/DifferentialPivotHousing.stl
3d-print/suspension/FrontWheelConnector.stl
3d-print/suspension/MiddleWheelConnector.stl
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

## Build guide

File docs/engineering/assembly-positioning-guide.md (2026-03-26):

# Mars Rover Phase 1 — Assembly Positioning Guide

## Coordinate System

| Axis | Direction | Positive |
|---|---|---|
| X | Left-Right | +X = Right (viewed from behind) |
| Y | Front-Back | +Y = Forward |
| Z | Up-Down | +Z = Up |
| Origin | Centre of body, at ground level (Z=0) | |

All values in **mm** unless stated. Fusion 360 uses **cm** internally (divide by 10).

---

## 1. Overall Envelope (0.4 scale)

| Parameter | mm | cm (Fusion) |
|---|----|---|
| Body length (Y) | 440 | 44.0 |
| Body width (X) | 260 | 26.0 |
| Body height (Z) | 120 | 12.0 |
| Ground clearance | 60 | 6.0 |
| Body bottom Z | 60 | 6.0 |
| Body top Z | 180 | 18.0 |
| Track width (wheel-to-wheel) | 280 | 28.0 |
| Wheelbase (front-to-rear) | 360 | 36.0 |
| Wheel diameter | 80 | 8.0 |
| Wheel width | 32 | 3.2 |

---

## 2. Wheel Positions (6 wheels)

Centre of each wheel hub. Z=40mm = wheel radius (sitting on ground Z=0).

| Wheel | X (mm) | Y (mm) | Z (mm) | Steered? | Rotation |
|---|---|---|---|---|---|
| Front-Left (FL) | -140 | +180 | 40 | Yes | 90° around Y (hub faces left) |
| Front-Right (FR) | +140 | +180 | 40 | Yes | -90° around Y (hub faces right) |
| Middle-Left (ML) | -140 | 0 | 40 | No | 90° around Y |
| Middle-Right (MR) | +140 | 0 | 40 | No | -90° around Y |
| Rear-Left (RL) | -140 | -180 | 40 | Yes | 90° around Y |
| Rear-Right (RR) | +140 | -180 | 40 | Yes | -90° around Y |

Wheels are revolve solids around Z in STL. Need 90° Y rotation to orient hub outward.

---

## 3. Body Quadrants (4 from 1 STL)

STL `BodyQuadrant.stl` bounding box: X=[-131,0], Y=[0,226], Z=[0,120] mm.
Origin at body centre, extends -X (left) and +Y (forward).

| Quadrant | Translation (mm) | Rotation | Coverage |
|---|---|---|---|
| FL | (0, 0, 60) | none | X[-131,0], Y[0,226] |
| FR | (+131, 0, 60) | none | X[0,131], Y[0,226] |
| RL | (0, -226, 60) | none | X[-131,0], Y[-226,0] |
| RR | (+131, -226, 60) | 180° Z | X[0,131], Y[-226,0] |

Note: FR and RL are translation-only (T&G won't visually mate perfectly, acceptable for assembly view). RR uses 180° Z rotation for correct diagonal mirror.

Top deck tiles follow same pattern at Z = 60+120 = 180mm.
STL `TopDeck.stl` bounding box: ~133x223x10mm.

---

## 4. Suspension Pivots — The Spine

### Diff Bar (through-bar design)
- 300mm 8mm steel rod, horizontal along X axis
- At Z = **120mm** (body mid-height, NOT 60mm)
- Spans X = -130 to +130mm
- Central 608ZZ bearing at (0, 0, 120)
- Side 608ZZ bearings at (±125, 0, 120) — in body walls

### Rocker Hub Connectors (×2)
- Clamped to diff bar at rocker pivot
- **Position**: (±125, 0, 120)
- Part size: ~45×40×35mm
- Diff bar bore: 8.0mm press-fit
- Front tube socket: angled ~15° down toward front wheel
- Rear tube socket: angled ~20° down toward bogie pivot

### Bogie Pivot Connectors (×2)
- 608ZZ bearing for bogie rotation
- **Position**: (±125, -90, ~55)
- Part size: ~45×35×30mm
- 3 tube sockets: from rocker, to middle wheel, to rear wheel

---

## 5. How Parts Connect — Mating Interfaces

### 5.1 Tube-in-Socket (8mm rods)

All suspension arms are 8mm steel rods inserted into printed connectors.

```
[Connector] ←── 8.2mm bore, 15mm deep ←── [8mm rod] ──→ 8.2mm bore, 15mm deep ──→ [Connector]
                 M3 grub screw retains                    M3 grub screw retains
```

- Socket bore: 8.2mm (0.2mm clearance for slide-fit)
- Socket depth: 15mm
- Retention: M3 grub screw through socket wall

### 5.2 Bolt-Through-to-Heat-Set (M3 fasteners)

**Connectors** have heat-set inserts (brass, melted into PLA at 170°C).
**Brackets/mounts** have M3 clearance holes (3.2mm) and bolt through into the inserts.

| Joint | Connector (has inserts) | Bracket (has through-holes) | Bolt Spacing |
|---|---|---|---|
| Steering bracket → FW connector | FrontWheelConnector front face | SteeringBracket | 20mm |
| Servo mount → FW connector | FrontWheelConnector side face | ServoMount | 20mm |
| Fixed mount → MW connector | MiddleWheelConnector mount face | FixedWheelMount | 16mm |

Insert dimensions: 4.8mm bore × 5.5mm deep, 0.5mm entry chamfer.

### 5.3 Bearing Seat (608ZZ)

```
[Housing wall]
  |── 22.15mm bore × 7.2mm deep (bearing press-fits in)
  |── 0.3mm × 45° entry chamfer
  |── 8.1mm through-bore (shaft passes through bearing)
```

### 5.4 Steering Pivot (per steered wheel)

```
                    ┌─────────────────────┐
                    │  Steering Bracket    │ ← bolted to FW Connector front face
                    │  ┌───────────────┐  │
                    │  │ 608ZZ bearing  │  │ ← press-fit in bracket top
                    │  └───────┬───────┘  │
                    │          │ 8mm shaft │ ← 50mm cut rod
                    │  Hard stop channel  │ ← 70° open arc at bottom
                    └──────────┼──────────┘
                               │
                    ┌──────────┼──────────┐
                    │  Steering Knuckle   │ ← hangs on pivot shaft
                    │  - 8.2mm pivot bore │
                    │  - Hard stop tab    │ ← sweeps in bracket channel (±35°)
                    │  - Steering arm     │ ← 15mm lateral, M2 hole for horn link
                    │  - N20 motor clip   │ ← holds drive motor
                    │  - 4mm axle bore    │ ← wheel axle
                    └─────────────────────┘
```

### 5.5 Steering Linkage (4-bar, per steered wheel)

```
    Servo shaft (in ServoMount)          Steering pivot (in bracket)
         │                                      │
         │ 15mm (SG90 horn arm)                 │ 15mm (knuckle steering arm)
         ▼                                      ▼
    Horn tip ─────── 20mm HornLink ──────── Arm tip
              (M2 pin)              (M2 pin)
```

- Servo-to-pivot horizontal offset: 20mm
- Angular ratio: ~1:1
- ServoMount sits on the SIDE face of the FrontWheelConnector

---

## 6. Suspension Arm Routing (Left Side)

All positions approximate for visual assembly:

```
                        Front Wheel FL (-140, +180, 40)
                              │
                         [FW Connector] at ~(-120, +180, 60)
                              │ 150mm rod, angled down
                              │
    Diff Bar ──────── [Rocker Hub] at (-125, 0, 120) ──── 608ZZ in body wall
    (Z=120)                   │
                              │ 60mm rod, angled down
                              │
                         [Bogie Pivot] at (-125, -90, ~55)
                           /          \
                    60mm rod         60mm rod
                    /                      \
        [MW Connector]              [FW Connector]
        (-120, 0, 60)              (-120, -180, 60)
              │                          │
        Middle Wheel ML           Rear Wheel RL
        (-140, 0, 40)            (-140, -180, 40)
```

Right side is symmetric (positive X).

---

## 7. Connector Positions (Assembly Coordinates)

These are the positions to use in the assembly script. All in mm.

### Wheel Connectors (at end of arm tubes, between body and wheel)

| Part | X | Y | Z | Notes |
|---|---|---|---|---|
| FW Conn FL | -120 | +180 | 60 | ~20mm inboard of wheel centre |
| FW Conn FR | +120 | +180 | 60 | |
| MW Conn ML | -120 | 0 | 60 | |
| MW Conn MR | +120 | 0 | 60 | |
| FW Conn RL | -120 | -180 | 60 | Rear steered wheels use same connector |
| FW Conn RR | +120 | -180 | 60 | |

### Suspension Connectors

| Part | X | Y | Z | Notes |
|---|---|---|---|---|
| Rocker Hub L | -125 | 0 | 120 | On diff bar, body mid-height |
| Rocker Hub R | +125 | 0 | 120 | |
| Bogie Pivot L | -125 | -90 | 55 | Below rocker, between mid and rear |
| Bogie Pivot R | +125 | -90 | 55 | |
| Diff Pivot Housing | 0 | 0 | 120 | Body centre, same Z as rockers |

### Steering Sub-Assembly (per corner, relative to wheel connector)

The steering bracket bolts to the **front face** of the wheel connector.
The servo mount bolts to the **side face** of the wheel connector.
The knuckle hangs **below** the bracket on the pivot shaft.

| Part | Offset from Connector | Notes |
|---|---|---|
| Steering Bracket | flush on front face, centred | Same X,Y as connector, same Z |
| Servo Mount | flush on side face, offset 20mm in X toward body | X ± 20mm from connector |
| Steering Knuckle | below bracket, -25mm Z | Hangs on pivot shaft |
| Horn Link | between servo horn tip and knuckle arm tip | ~10mm in front of connector |

### Steering Absolute Positions (FL corner example)

| Part | X | Y | Z |
|---|---|---|---|
| FW Connector FL | -120 | +180 | 60 |
| Steering Bracket FL | -120 | +180 | 60 |
| Servo Mount FL | -100 | +180 | 60 |
| Knuckle FL | -120 | +180 | 35 |
| Horn Link FL | -110 | +182 | 55 |

For FR: mirror X signs. For RL/RR: mirror Y signs (and X for RR).

### Fixed Wheel Mounts (middle wheels)

| Part | X | Y | Z |
|---|---|---|---|
| Fixed Mount ML | -120 | 0 | 60 |
| Fixed Mount MR | +120 | 0 | 60 |

Bolted to the mount face of MiddleWheelConnector.

---

## 8. Internal Components

All inside the body cavity (Z = 60 to 180mm).

| Part | X | Y | Z | Notes |
|---|---|---|---|---|
| Electronics Tray | 0 | +50 | 63 | On body floor, toward front |
| Battery Tray | 0 | -80 | 63 | On body floor, toward rear |
| Fuse Holder | +50 | -50 | 63 | Near battery |
| Switch Mount | -130 | +100 | 120 | On left body side wall, mid-height |
| Strain Relief 1 | -125 | 0 | 120 | At left rocker pivot exit |
| Strain Relief 2 | +125 | 0 | 120 | At right rocker pivot exit |

---

## 9. Diff Links and Cable Clips

### Diff Links (×2)
Through-bar design means these may be vestigial (bar IS the pivot). If included:

| Part | X | Y | Z |
|---|---|---|---|
| Diff Link L | -62 | 0 | 118 |
| Diff Link R | +62 | 0 | 118 |

### Cable Clips (×4 representative, many more in reality)

Along the arm tubes at ~80mm intervals:

| Part | X | Y | Z |
|---|---|---|---|
| Clip L-front-1 | -125 | +60 | 100 |
| Clip L-front-2 | -125 | +120 | 80 |
| Clip R-front-1 | +125 | +60 | 100 |
| Clip R-front-2 | +125 | +120 | 80 |

---

## 10. Bearings (9 total)

| # | Location | Position (mm) | In Part |
|---|---|---|---|
| 1 | Body left wall | (-125, 0, 120) | BodyQuadrant (pivot boss) |
| 2 | Body right wall | (+125, 0, 120) | BodyQuadrant (pivot boss) |
| 3 | Body centre | (0, 0, 120) | DiffPivotHousing |
| 4 | Left bogie | (-125, -90, 55) | BogiePivotConnector |
| 5 | Right bogie | (+125, -90, 55) | BogiePivotConnector |
| 6 | Steering FL | (-120, +180, 60) | SteeringBracket |
| 7 | Steering FR | (+120, +180, 60) | SteeringBracket |
| 8 | Steering RL | (-120, -180, 60) | SteeringBracket |
| 9 | Steering RR | (+120, -180, 60) | SteeringBracket |

---

## 11. Key Insight: What Touches What

### Parts that DIRECTLY CONTACT each other:

1. **Body quadrants** touch each other at T&G joints along X=0 and Y=0
2. **Top deck tiles** sit on top of body quadrants (snap clips)
3. **Diff bar rod** passes through: DiffPivotHousing → body wall bearings → RockerHubConnectors
4. **Arm rods** slide into tube sockets on connectors (15mm insertion each end)
5. **Steering bracket** bolts flush to FrontWheelConnector front face
6. **Servo mount** bolts flush to FrontWheelConnector side face
7. **Knuckle** hangs from steering bracket via 8mm pivot shaft + bearing
8. **Horn link** pins between servo horn tip and knuckle steering arm
9. **Fixed wheel mount** bolts flush to MiddleWheelConnector mount face
10. **Electronics tray** sits on body floor (clips or standoffs)
11. **Battery tray** sits on body floor
12. **Cable clips** clamp around 8mm arm tubes

### Parts that need GAPS (clearance):

1. Wheels ↔ body side walls: minimum 10mm
2. Knuckle hard stop tab ↔ bracket channel walls: 0.5mm either side
3. Horn link ↔ connector body: minimum 2mm at full steering lock
4. Servo horn ↔ bracket wall: minimum 2mm
5. Rocker arms ↔ body walls at full articulation: minimum 3mm

---

## 12. Assembly Script Constants (corrected, in cm)

```python
# Body
BODY_L = 44.0       # 440mm
BODY_W = 26.0       # 260mm
BODY_H = 12.0       # 120mm
GROUND_Z = 6.0      # 60mm

# Wheels
TRACK_HALF = 14.0   # 140mm
WB_HALF = 18.0      # 180mm
WHEEL_R = 4.0       # 40mm
WHEEL_W = 3.2       # 32mm
WHEEL_Z = 4.0       # 40mm (wheel centre)

# Suspension pivots — CORRECTED
DIFF_Z = 12.0       # 120mm — body mid-height (NOT 6.0!)
ROCKER_X = 12.5     # 125mm
BOGIE_Y = -9.0      # -90mm
BOGIE_Z = 5.5       # 55mm (NOT 4.0!)

# Connector positions
CONN_X = 12.0       # 120mm — ~20mm inboard of wheel centre
CONN_Z = 6.0        # 60mm — at body bottom height
```

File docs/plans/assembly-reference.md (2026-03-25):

# Phase 1 Assembly Reference Guide

## Overview

9 sub-assembly stages from individual parts to rolling rover.
Each stage is self-contained and testable before proceeding.

**Total assembly time: ~6-7 hours** (after all parts printed and hardware ready)

| Stage | Description | Time Estimate |
|---|---|---|
| 1 | Prepare printed parts (clean, inserts, shafts) | ~30 min |
| 2 | Wheel sub-assemblies (x6) | ~30 min |
| 3 | Bogie arms (x2) | ~20 min |
| 4 | Steering brackets + servos (x4) | ~45 min |
| 5 | Front wheel assemblies (x2) | ~20 min |
| 6 | Rocker-bogie suspension (x2) | ~30 min |
| 7 | Body frame | ~30 min |
| 8 | Final assembly — suspension to body | ~30 min |
| 9 | Electronics and wiring | ~90 min + 60 min testing |

---

## Tools Required

Gather everything before starting. Missing a tool mid-stage is frustrating.

### Assembly Tools
- M3 Allen key (2.5mm hex) -- body seams, rocker halves, servo mounts
- M2 Allen key (1.5mm hex) -- wheel grub screws
- Small Phillips screwdriver -- servo horn screws
- Soldering iron with fine tip -- heat-set inserts at 170-180C for PLA
- Tweezers / needle-nose pliers -- placing small hardware, routing wires
- Blue painter's tape -- temporary fixturing, labelling wire pairs

### Electrical Tools
- Multimeter -- continuity checks before powering, voltage verification
- Wire strippers -- 22-26 AWG range
- Crimping tool -- JST-XH connectors (2-pin motor, 3-pin servo)
- Solder + flux -- 100nF capacitors on motor terminals, wire repairs

### Measurement & Verification
- Kitchen scale -- weight verification of sub-assemblies
- Ruler / digital calipers -- dimensional checks, bearing seat verification
- USB-C cable -- ESP32-S3 programming and serial debug
- Phone with WiFi -- PWA control testing (connect to rover AP)

### Consumables
- 100nF ceramic capacitors (x6, already on shopping list)
- Heat-shrink tubing (assorted 2-5mm)
- Cable ties (small, 100mm)
- Isopropyl alcohol (cleaning bearing seats)

---

## Stage 1: Prepare Printed Parts (~30 min)

### 1.1 Clean and Inspect
- Remove all brims and support material
- Trim stringing with flush cutters
- Test-fit all 608ZZ bearing seats with a bearing (should press in firmly)
- Test-fit N20 motor shaft in wheel hub bore

### 1.2 Install Heat-Set Inserts

**Temperature: 170-180C** (PLA -- do NOT use PETG's 220C)

| Part | Insert Count | Locations |
|---|---|---|
| Body quadrant FL | ~6 | X-seam + Y-seam edges |
| Body quadrant FR | ~6 | X-seam + Y-seam edges |
| Body quadrant RL | ~6 | X-seam + Y-seam edges |
| Body quadrant RR | ~6 | X-seam + Y-seam edges |
| Steering brackets (x4) | 2 each | Arm mounting faces |
| Fixed wheel mounts (x2) | 2 each | Arm mounting faces |
| Servo mounts (x4) | 2 each | Bracket attachment |
| Top deck FR tile | 4 | Phone mount bosses |

**Technique**: Place insert on hole. Press iron straight down. Wait 2-3 seconds. Pull iron straight out. Let cool 10 seconds. Insert should be flush with surface.

### 1.3 Prepare Shaft Hardware
- Cut 8mm steel rod to 300mm length (differential bar)
- Deburr ends with file
- Test through 608ZZ bore (should slide freely)

### Troubleshooting -- Stage 1
- **Insert goes in crooked**: Let it cool, then reheat and straighten. If badly misaligned, use iron to melt it out and press in a fresh insert.
- **Insert sits proud (above surface)**: Press iron down again gently until flush. Do not force -- PLA will deform around the insert.
- **Bearing seat too tight**: Slightly ream hole with a round file or wrap 220-grit sandpaper around a dowel. Remove material slowly. Never hammer a bearing in -- PLA will crack.
- **Bearing seat too loose**: Apply a thin coat of CA (superglue) to the bore, let it cure 5 minutes, then press bearing in. This is a one-time fix -- the bearing will be permanent.

> **TEST GATE**: All heat-set inserts flush. All bearing seats accept 608ZZ with firm hand pressure. All shaft sections slide through bearing bores freely.

---

## Stage 2: Wheel Sub-Assemblies x6 (~30 min)

### Parts per wheel:
- 1x PLA rim (rover_wheel.py)
- 1x TPU tire (rover_tire.py) -- if available
- 1x N20 motor (GA12-N20 6V 100RPM)
- 1x M2 x 4mm grub screw

### Assembly:
1. If using TPU tires: press TPU tire onto PLA rim (rim lips retain tire)
2. Solder 100nF ceramic capacitor across motor terminals (do all 6 motors now)
3. Insert N20 motor D-shaft into wheel hub bore
4. Align D-flat on shaft with flat in bore
5. Thread M2 grub screw into radial hole, tighten against shaft D-flat

### Verify:
- [ ] Wheel spins freely on motor shaft
- [ ] No wobble (D-flat aligned)
- [ ] Grub screw holds wheel firmly (try to pull wheel off by hand -- should not budge)
- [ ] Tire seated between both rim lips (if using TPU)
- [ ] 100nF capacitor soldered to EVERY motor (noise suppression)

### Troubleshooting -- Stage 2
- **Wheel wobbles on shaft**: D-flat not aligned. Loosen grub screw, rotate wheel until D-flat seats, retighten.
- **Grub screw won't grip**: Shaft may have rotated past the D-flat. Use calipers to find the flat side, align, retighten.
- **TPU tire won't seat**: Warm the tire slightly (hair dryer, 30 seconds) to make it more pliable. Stretch over rim lips.
- **Motor shaft too loose in bore**: Wrap one layer of painter's tape around the shaft as a shim. Or apply a drop of threadlocker.

> **TEST GATE**: All 6 wheels spin freely by hand with no wobble. Grub screws hold firm. Capacitors soldered on all 6 motors.

---

## Stage 3: Bogie Arms x2 -- left and right (~20 min)

### Parts per bogie:
- 1x Bogie pivot connector (bogie_pivot_connector.py)
- 2x 8mm steel tube sections (cut to length per EA-25)
- 1x 608ZZ bearing (centre pivot)
- 2x Wheel sub-assemblies (middle + rear)

### Assembly:
1. Press 608ZZ bearing into bogie arm centre pivot boss
2. Snap N20 motors into motor clip pockets at each end
3. Route motor wires through wire slot alongside pivot boss

### Verify:
- [ ] Bearing seated flush in boss
- [ ] Both motors snap-fit securely (should click in, not fall out when inverted)
- [ ] Wheels spin freely
- [ ] Wire routing doesn't bind when bogie pivots

### Troubleshooting -- Stage 3
- **Bearing won't press in**: Slightly ream hole with round file. Remove material gradually -- 0.1mm at a time. Never force -- PLA will crack.
- **Motor doesn't clip in**: Check for brim remnants in the clip pocket. Clean with a craft knife. Motor should snap in with moderate thumb pressure.
- **Wires snag on pivot**: Re-route wires through the dedicated wire channel. Use a small cable tie at the pivot to keep wires constrained but with enough slack to allow full articulation.

> **TEST GATE**: Each bogie arm pivots freely on 608ZZ bearing with no binding. Acceptable play: <0.5mm axial. Both motors held securely. Wires do not bind through full pivot range.

---

## Stage 4: Steering Assemblies x4 (~45 min)

*Updated per EA-27: steering bracket is now a bearing carrier only (no motor clip).
Motor is in the knuckle. Horn link provides the servo-to-knuckle connection.*

### Parts per steered wheel:
- 1x Steering bracket (steering_bracket.py — bearing carrier + hard stops)
- 1x 608ZZ bearing (pivot bearing)
- 1x 8mm steel rod segment (~50mm, steering pivot shaft)
- 1x SG90 servo
- 1x Servo mount (servo_mount.py)
- 1x Steering knuckle (steering_knuckle.py — carries motor + wheel axle)
- 1x Steering horn link (steering_horn_link.py — 4-bar linkage coupler)
- 2x M2x10mm screws (link pin joints)
- 2x M2 nyloc nuts (link pin retention)
- 4x M2 nylon washers (smooth rotation at pins)

### Assembly:
1. Press 608ZZ bearing into bracket top bore (C-clamp, flush with top face)
2. Insert 8mm pivot rod through bracket bore + bearing inner race
3. Bolt servo mount to front wheel connector side face (2x M3x12 into heat-set inserts)
4. Insert SG90 servo into mount pocket, secure with 2x M2x8 Phillips screws
5. Attach single-arm horn to SG90 spline (centred = straight ahead), tighten horn screw
6. Snap N20 motor into knuckle motor pocket (shaft exits through axle bore side)
7. Slide knuckle pivot socket over pivot rod (rod protrudes below bracket)
8. Tighten M3 grub screw in knuckle socket to retain rod
9. Connect horn link:
   - Horn end: M2x10 → nylon washer → horn hole → link hole → nylon washer → M2 nyloc nut
   - Knuckle arm end: same hardware to knuckle steering arm M2 hole
   - Finger-tight + 1/4 turn — pins must rotate freely
10. Bolt steering bracket to connector front face (2x M3x12 into heat-set inserts)

### Verify:
- [ ] Bearing seated, pivot shaft rotates freely (flick inner race)
- [ ] Servo centred at 1500us — horn perpendicular to bracket
- [ ] Horn link operates smoothly (manually sweep ±35°)
- [ ] Hard stops engage at ±35° — knuckle tab contacts bracket walls
- [ ] Motor spins freely in knuckle pocket
- [ ] Motor wires have 15mm slack loop for steering sweep

### Troubleshooting -- Stage 4
- **Servo jitters at rest**: Check power supply. Likely 5V BEC voltage droop under load (see EA-19). Try powering servo from a separate 5V source to confirm.
- **Horn link binds**: Pin joints too tight. Loosen M2 nyloc 1/8 turn. Nylon washers essential for smooth rotation.
- **Hard stops don't engage at ±35°**: Tab or walls may be under-printed. Verify with protractor. Sand if too tall, add shim if too short.
- **Servo doesn't respond**: Check 3-pin wiring order: Brown=GND, Red=5V, Orange=Signal.
- **Bearing feels gritty**: Spin bearing 30 seconds to distribute grease. Flush with IPA if persistent.

> **TEST GATE**: Command each servo to 1111us (−35°), 1500us (centre), 1889us (+35°). Verify smooth motion through full range. Hard stops engage. Horn link operates freely. All 4 assemblies done.

---

## Stage 5: Steered Wheel Assemblies x4 (~20 min)

*Updated per EA-27: motor is now in the knuckle (not the bracket).
All 4 steered wheels follow the same assembly (FL, FR, RL, RR).*

### Parts per wheel:
- 1x Steering assembly (from Stage 4)
- 1x Wheel sub-assembly (from Stage 2)

### Assembly:
1. Motor is already in the knuckle from Stage 4
2. Insert motor D-shaft through knuckle axle bore
3. Press wheel hub bore onto motor D-shaft
4. Tighten M2 grub screw against D-flat

### Verify:
- [ ] Wheel turns with motor (driving) — spin by hand, check motor shaft engagement
- [ ] Wheel turns with servo (steering) — manually rotate horn link
- [ ] No mechanical interference through full ±35° steering range
- [ ] Wheel doesn't hit arm tube at full lock (≥5mm gap per EA-08)
- [ ] Motor wires have adequate slack through full steering sweep

### Troubleshooting -- Stage 5
- **Wheel wobbles**: D-flat not aligned in hub bore. Loosen grub screw, rotate wheel until D-flat seats.
- **Wheel hits bracket when steered**: Motor not fully seated in knuckle clip. Check for brim remnants in pocket.
- **Motor wire pulls tight at full steer**: Route wire through connector wire exit hole with 15mm slack loop. Secure with zip-tie anchor at neutral position.

> **TEST GATE**: Each steered wheel drives smoothly while steering through full ±35° range. No mechanical interference. Wires have adequate slack. All 4 steered wheels + 2 fixed wheels = 6 total ready for suspension assembly.

---

## Stage 6: Rocker-Bogie Suspension x2 -- left and right (~30 min)

### Parts per side:
- 1x Rocker hub connector (rocker_hub_connector.py)
- 2x 8mm steel tube sections (front + rear rocker tubes per EA-25)
- 1x Bogie arm sub-assembly (from Stage 3)
- 1x Front wheel assembly (from Stage 5)
- 1x Fixed wheel mount (fixed_wheel_mount.py) -- for rear-most steered wheel
- M3 bolts for joining rocker halves
- 8mm shaft sections for pivot pins

### Assembly:
1. Bolt rocker arm front + rear halves together (M3 x 12mm into heat-set inserts)
2. Insert 8mm pivot pin through rocker and bogie arm bearing
3. Attach front wheel assembly to rocker arm front via 8mm pivot
4. Attach fixed wheel mount to rear steered wheel position

### Verify:
- [ ] Bogie pivots freely on rocker
- [ ] All 3 wheels on this side touch a flat surface simultaneously
- [ ] Suspension articulates smoothly over ~20mm obstacle
- [ ] No binding or interference at any position

### Troubleshooting -- Stage 6
- **Bogie doesn't pivot freely**: Check 8mm shaft for burrs. Deburr with file. Verify bearing inner race spins on shaft (bearing may have been pressed onto shaft too tightly).
- **Wheels don't all touch ground**: One pivot may be binding. Work through each joint individually. The most common cause is a bearing that isn't fully seated.
- **Rocker halves don't align**: Bolt holes between halves may be slightly misaligned. Ream with a 3mm drill bit if necessary. Do not over-torque -- the heat-set inserts will pull out.

> **TEST GATE**: Place each suspension side on a flat surface. All 3 wheels touch. Push one end down 20mm -- the other end lifts smoothly. Suspension returns to level when released. No binding at any position.

---

## Stage 7: Body Frame (~30 min)

### Parts:
- 4x Body quadrants (FL, FR, RL, RR)
- 3mm dowel pins (alignment)
- M3 x 12mm bolts (into seam heat-set inserts)

### Assembly:
1. Dry-fit all 4 quadrants -- check alignment with dowel pins
2. Join FL + FR (X-seam bolts)
3. Join RL + RR (X-seam bolts)
4. Join front pair to rear pair (Y-seam bolts)
5. Verify all seams flush and square

### Verify:
- [ ] All 4 quadrants flush at seams
- [ ] Body frame is square (measure diagonals -- should be equal within 2mm)
- [ ] Rocker pivot bores on RL/RR sides accessible
- [ ] Kill switch hole (RR) is clear
- [ ] Cable exit holes aligned
- [ ] LED underglow holes (4x) in floor are clear
- [ ] Headlight holes (FL/FR) and taillight holes (RL/RR) are clear

### Troubleshooting -- Stage 7
- **Body quadrants don't align**: Check dowel pin holes are clear of print debris. Sand dowel pins lightly if needed. Don't force -- PLA corners will crack.
- **Seams not flush**: One quadrant may have warped during printing. Place on a flat surface and check for rock. If warped, try clamping with painter's tape and running a heat gun briefly over the seam (be very careful with PLA -- it softens at ~60C).
- **Diagonal measurements off by >3mm**: Loosen all bolts, re-seat dowel pins, and re-tighten in a star pattern (FL-RR, FR-RL, then seams).

> **TEST GATE**: Body frame sits flat on table with no rock. Diagonals equal within 2mm. All pivot bores and cable holes are clear and accessible.

---

## Stage 8: Final Assembly -- Suspension to Body (~30 min)

### Assembly:
1. Insert 8mm pivot pins through body rocker pivot bores
2. Attach left suspension assembly to left body pivots
3. Attach right suspension assembly to right body pivots
4. Insert differential bar through body centre, connecting left and right rockers
5. Secure diff bar with printed adapters at each end

### Verify:
- [ ] Rover sits level on flat surface
- [ ] All 6 wheels touch ground simultaneously
- [ ] Push down on one corner -- opposite wheels lift smoothly
- [ ] Differential bar allows body to remain level while wheels articulate
- [ ] Body height is correct (~80mm ground clearance at 0.4 scale)

### Troubleshooting -- Stage 8
- **Not all 6 wheels touch ground**: One suspension side may be binding. Remove from body and re-check Stage 6 test gate. Also verify diff bar adapters aren't clamping the bar too tightly.
- **Differential bar too short**: The 300mm rod should span the 250mm rocker pivot span with 25mm overhang each side. If it doesn't reach, measure actual span and recut.
- **Body rocks on flat surface**: Differential bar may be binding. Ensure it rotates freely in the body centre bore. Lubricate with a drop of light machine oil if needed.

> **TEST GATE**: Place rover on flat surface -- all 6 wheels touch. Place one wheel on a 20mm book -- rover remains stable, no wheels lift off. Differential bar rotates smoothly. Ground clearance ~80mm.

---

## Stage 9: Electronics and Wiring (~90 min assembly + 60 min testing)

### Parts:
- 1x Electronics tray
- 1x ESP32-S3 DevKitC-1
- 2x L298N motor drivers
- 1x 2S LiPo 2200mAh
- 1x Power switch
- 1x 5A fuse + holder
- Jumper wires, strain relief clips

### Assembly:
1. Mount ESP32 on tray standoffs (M2.5 screws)
2. Mount L298N drivers on tray standoffs
3. Place LiPo in battery cradle, secure with strap
4. Wire per EA-19 wiring diagram:
   - Battery -> switch -> fuse -> L298N VCC
   - L298N -> motors (solder 100nF caps across motor terminals first!)
   - ESP32 GPIO -> L298N IN1-IN4 (see EA-09 pin map)
   - ESP32 -> servos (signal + 5V from L298N regulator)
5. Route wires through cable channels
6. Secure with strain relief clips at exit points
7. **STOP: Pre-power checks (see below)**
8. Place tray inside body frame
9. Attach top deck tiles (snap clips)

### Pre-Power Safety Checks (MANDATORY)
Before connecting battery for the first time:
1. Multimeter continuity: check there is NO short between battery +/- terminals
2. Multimeter continuity: verify each motor connects to correct L298N output pair
3. Visual inspection: no bare wire touching chassis or other wires
4. Verify fuse is installed in holder
5. Verify E-stop switch is in the OFF position

### First Power-Up Sequence:
1. Connect USB-C to ESP32 first (powers ESP32 only, no motors)
2. Verify serial output on computer (115200 baud)
3. Verify WiFi AP "MarsRover" appears on phone
4. Connect phone to AP, open PWA
5. NOW connect battery (with E-stop OFF / switch off)
6. Turn on switch -- verify battery voltage reading on PWA
7. Test one motor at a time: low speed, forward, then reverse
8. Test one servo at a time: centre, left, right
9. If anything is wrong, hit E-stop immediately

### Verify:
- [ ] No short circuits (multimeter continuity check before powering)
- [ ] Battery voltage correct (7.4-8.4V)
- [ ] ESP32 boots and creates WiFi AP
- [ ] All 6 motors respond to commands (correct direction)
- [ ] All 4 servos sweep correctly (+/-35 degrees)
- [ ] E-stop (kill switch) cuts power instantly
- [ ] Battery voltage telemetry displays on phone PWA
- [ ] All 3 steering modes work (Ackermann, point turn, crab walk)

### Troubleshooting -- Stage 9
- **ESP32 won't boot**: Check USB-C cable is data-capable (not charge-only). Try a different cable. Check for solder bridges on ESP32 pins.
- **WiFi won't connect**: Check ESP32 is in AP mode. Default SSID: "MarsRover". Try restarting phone WiFi. Try forgetting the network and reconnecting. If SSID doesn't appear, check serial output for boot errors.
- **Motor runs backwards**: Swap the two motor wires at the L298N output terminals. Do NOT change firmware -- physical wiring fix is simpler and more reliable.
- **Motor doesn't run at all**: Check L298N enable jumper is in place. Check 100nF capacitor isn't shorting motor terminals. Measure voltage at L298N output with multimeter.
- **Servo jitters at rest**: Likely 5V supply issue. L298N 5V regulator may not provide enough current for 4 servos simultaneously. Test with fewer servos connected. May need separate 5V BEC (see EA-19).
- **Battery voltage reads wrong**: Check voltage divider resistor values on ADC input (see EA-09). Calibrate ADC_VDIV_RATIO in config.h.
- **E-stop doesn't work**: Check switch wiring. Switch should be in series with battery positive lead, BEFORE the fuse.
- **Servo doesn't centre correctly**: Adjust SERVO_CENTRE_TRIM in config.h. Each servo may need individual trim of +/-50us.
- **Steering seems reversed (left command turns right)**: Swap SERVO_FL/SERVO_FR pin assignments in config.h. Or physically swap the servo connectors.

> **TEST GATE**: Full system operational. All motors drive correct direction. All servos steer correct direction. WiFi connected from phone. PWA displays telemetry. E-stop kills power. Battery voltage reading accurate. Rover drives forward in a straight line (trim motors if needed via MOTOR_TRIM constants).

---

## Post-Assembly Checklist

Run through this complete checklist before declaring the build "done":

### Mechanical
- [ ] All 6 wheels spin freely by hand
- [ ] Suspension articulates without binding
- [ ] Body frame is rigid (no flex at seams)
- [ ] Electronics tray secure inside body
- [ ] All wires routed, no pinch points
- [ ] Top deck snaps on cleanly
- [ ] Battery sits securely, no rattle
- [ ] No loose bolts (torque check all M3 joints)

### Electrical
- [ ] WiFi connects from phone within 5 seconds
- [ ] Forward/reverse/left/right all work
- [ ] Steering angles look correct (not reversed)
- [ ] Point turn mode works (front wheels opposite to rear)
- [ ] Crab walk mode works (all wheels same angle)
- [ ] Speed slider affects all motors proportionally
- [ ] E-stop cuts all power immediately
- [ ] Battery voltage telemetry is accurate (+/-0.2V of multimeter reading)

### Weight Verification
- [ ] Weigh completed rover on kitchen scale
- [ ] Expected: ~1.1-1.3 kg (depending on battery and wiring)
- [ ] Record actual weight: _______ g

---

## Torque Sequence

| Joint | Fastener | Torque | Notes |
|---|---|---|---|
| Body seam | M3 x 12mm | 0.5 N-m max (finger tight + 1/4 turn) | Don't strip PLA insert |
| Rocker halves | M3 x 12mm | 0.5 N-m max (finger tight + 1/4 turn) | Same |
| Servo mount | M3 x 8mm | 0.5 N-m max | Into heat-set inserts |
| Servo horn | Servo screw | 0.2 N-m max (gentle) | Servo plastic is soft |
| Servo to mount | Small Phillips | 0.2 N-m max | Don't crack servo ears |
| Wheel grub | M2 x 4mm | Snug | Allen key 1.5mm, onto D-flat |
| ESP32 standoffs | M2.5 | Finger tight | Don't crack PCB |
| L298N standoffs | M3 | Finger tight + 1/4 turn | Check no shorts underneath |
| Diff bar adapters | M3 grub | Snug | If equipped |

**General rule for PLA heat-set inserts**: Finger tight + 1/4 turn maximum (0.5 N-m). PLA inserts strip or pull out easily. If an insert spins, remove the bolt, reheat the insert with the iron, press it in deeper, and let it cool before retrying.

---

## Quick Reference: Wire Colour Convention

Adopt a consistent colour scheme and label every wire pair. Suggested convention:

| Signal | Colour |
|---|---|
| Battery + | Red |
| Battery - | Black |
| Motor power A | Red/White stripe |
| Motor power B | Black/White stripe |
| Servo signal | Orange or Yellow |
| Servo 5V | Red |
| Servo GND | Brown |
| GPIO signals | Blue or Green |
| Ground bus | Black |

Label every JST connector with painter's tape and a marker (e.g., "M-LF" for motor left front, "S-RF" for servo right front).

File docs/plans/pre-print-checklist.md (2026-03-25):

# Pre-Print Verification Checklist

Before committing ~72 hours of print time, verify every CAD script, dimension, and interface.

**Printer**: CTC Bizer (225×145×150mm bed, PLA, x3g via GPX)
**Date**: 2026-03-25
**Version**: v3.0 (post EA-28 systems integration)
**Integration ref**: EA-28 (docs/engineering/28-systems-integration.md), EA-29 (CAD redesign)

---

## 1. CAD Script Execution Verification

29 STL exports from BatchExportAll across 6 stages. **All 29/29 STLs exported successfully** (2026-03-25, arc direction bug fixed and all STLs regenerated).

### Stage 1: Calibration (3 parts)

| # | Script | Export Name | Qty | Status |
|---|---|---|-----|---|
| 1 | `CalibrationTestCard` | calibration_test_card.stl | 1 | EXPORTED |
| 2 | `BearingTestPiece` | bearing_test_piece.stl | 1 | EXPORTED |
| 3 | `TubeSocketTest` | tube_socket_test.stl | 1 | EXPORTED |

### Stage 2: Wheels (2 scripts, 12 parts)

| # | Script | Export Name | Qty | Status |
|---|---|---|-----|---|
| 4 | `RoverWheelV3` | rover_wheel_v3.stl | 6 | EXPORTED |
| 5 | `RoverTire` | rover_tire.stl | 6 (TPU) | EXPORTED (CTC Bizer cannot print TPU — use O-rings or order externally) |

### Stage 3: Steering & Mounts (5 scripts, 18 parts)

| # | Script | Export Name | Qty | Status |
|---|---|---|-----|---|
| 6 | `SteeringBracket` | steering_bracket.stl | 4 | EXPORTED |
| 7 | `FixedWheelMount` | fixed_wheel_mount.stl | 2 | EXPORTED |
| 8 | `ServoMount` | servo_mount.stl | 4 | EXPORTED |
| 9 | `SteeringKnuckle` | steering_knuckle.stl | 4 | EXPORTED |
| 10 | `SteeringHornLink` | steering_horn_link.stl | 4 | EXPORTED |

### Stage 4: Suspension Connectors (6 scripts, 23 parts)

| # | Script | Export Name | Qty | Status |
|---|---|---|-----|---|
| 11 | `RockerHubConnector` | rocker_hub_connector.stl | 2 | EXPORTED |
| 12 | `BogiePivotConnector` | bogie_pivot_connector.stl | 2 | EXPORTED |
| 13 | `FrontWheelConnector` | front_wheel_connector.stl | 4 | EXPORTED |
| 14 | `MiddleWheelConnector` | middle_wheel_connector.stl | 2 | EXPORTED |
| 15 | `DifferentialPivotHousing` | differential_pivot_housing.stl | 1 | EXPORTED |
| 16 | `CableClip` | cable_clip.stl | 12 | EXPORTED |

### Stage 5: Body (2 scripts, 8 parts)

| # | Script | Export Name | Qty | Status |
|---|---|---|-----|---|
| 17a | `BodyQuadrant` (FL) | body_quadrant_fl.stl | 1 | EXPORTED |
| 17b | `BodyQuadrant` (FR) | body_quadrant_fr.stl | 1 | EXPORTED |
| 17c | `BodyQuadrant` (RL) | body_quadrant_rl.stl | 1 | EXPORTED (trimmed for bed fit) |
| 17d | `BodyQuadrant` (RR) | body_quadrant_rr.stl | 1 | EXPORTED (trimmed for bed fit) |
| 18a | `TopDeck` (FL) | top_deck_fl.stl | 1 | EXPORTED |
| 18b | `TopDeck` (FR) | top_deck_fr.stl | 1 | EXPORTED (phone mount bosses) |
| 18c | `TopDeck` (RL) | top_deck_rl.stl | 1 | EXPORTED |
| 18d | `TopDeck` (RR) | top_deck_rr.stl | 1 | EXPORTED |

### Stage 6: Small Parts (3 scripts, 12 parts)

| # | Script | Export Name | Qty | Status |
|---|---|---|-----|---|
| 19 | `ElectronicsTray` | electronics_tray.stl | 1 | EXPORTED |
| 20 | `StrainReliefClip` | strain_relief_clip.stl | 10 | EXPORTED |
| 21 | `FuseHolderBracket` | fuse_holder_bracket.stl | 1 | EXPORTED |
| 22 | `SwitchMountPlate` | switch_mount_plate.stl | 1 | EXPORTED |

**Total: 29 STL exports, ~76 printed parts** (excluding TPU tires)

> **BatchExportAll Status**: COMPLETE (2026-03-25). All 29/29 STLs exported successfully after CAD redesign. Arc direction bug was fixed and all STLs regenerated. All scripts now include fillets, chamfers, and use shared `cad_helpers.py` module. See EA-29 for full redesign documentation.

---

## 2. Hardware Fitment Verification

All dimensions from EA-28 Section 3 cross-domain interface matrix.

### 608ZZ Bearing Seats (9 locations — EA-28 M-01 to M-07)

| Location | Host Part | Bore | Depth | Boss OD | Status |
|---|---|---|---|---|---|
| Body L rocker pivot | body_quadrant RL | 22.15mm | 7.2mm | 30mm | Pending |
| Body R rocker pivot | body_quadrant RR | 22.15mm | 7.2mm | 30mm | Pending |
| Body diff centre | body (centre) | 22.15mm | 7.2mm | 30mm | Pending |
| L rocker-to-bogie | bogie_pivot_connector | 22.15mm | 7.2mm | 30mm | Pending |
| R rocker-to-bogie | bogie_pivot_connector | 22.15mm | 7.2mm | 30mm | Pending |
| FL steering pivot | steering_bracket | 22.15mm | 7.2mm | N/A | Pending |
| FR steering pivot | steering_bracket | 22.15mm | 7.2mm | N/A | Pending |
| RL steering pivot | steering_bracket | 22.15mm | 7.2mm | N/A | Pending |
| RR steering pivot | steering_bracket | 22.15mm | 7.2mm | N/A | Pending |

### Tube Socket Interfaces (all connectors — EA-28 M-04 to M-06)

| Feature | Dimension | Tolerance |
|---|---|---|
| Bore | 8.2mm | ±0.1mm |
| Depth | 15mm | ±0.5mm |
| M3 grub hole | 3.0mm × 6mm deep | ±0.1mm |
| Minimum wall | ≥4mm | — |

### N20 Motor Clips (6 locations)

| Part | Pocket (W×H×D) | Shaft Exit |
|---|---|---|
| steering_knuckle (×4) | 12.2×10.2×25mm | 4.0mm hole |
| fixed_wheel_mount (×2) | 12.2×10.2×25mm | 4.0mm hole + zip-tie |

### SG90 Servo Pockets (4 locations)

| Part | Pocket | Tab Span | M2 Holes | Horn Slot |
|---|---|---|---|---|
| servo_mount (×4) | 22.4×12.2×12mm | 32.4mm | 27.5mm spacing | 12mm circular |

### Heat-Set Insert Holes (~40 total)

All holes: **4.8mm diameter × 5.5mm deep** for M3 × 5.7mm OD brass inserts.
Install temperature: **170-180°C** (PLA — lower than PETG's 200-220°C).

### Shaft Bores

| Feature | Dimension | Parts |
|---|---|---|
| 608ZZ shaft bore | 8.1mm | All bearing locations |
| Wheel hub D-shaft | 3.1mm + 0.5mm D-flat | rover_wheel_v3 |
| D-shaft M2 grub screw | 2mm × 5mm deep radial | rover_wheel_v3 |

---

## 3. Bed Fit Verification

All parts must fit within CTC Bizer: **225×145×150mm**.

| Part | Largest Dimension | Bed Footprint | Fits? |
|---|---|---|---|
| body_quadrant_fl | 220×130×80mm | 220×130 | YES |
| body_quadrant_fr | 220×130×80mm | 220×130 | YES |
| body_quadrant_rl | ≤225×145×80mm | ≤225×145 | YES (trim cut applied) |
| body_quadrant_rr | ≤225×145×80mm | ≤225×145 | YES (trim cut applied) |
| electronics_tray | 120×180×18mm | 180×120 | YES |
| rover_wheel_v3 | 86×86×32mm | 86×86 | YES |
| rocker_hub_connector | ~45×40×35mm | 45×40 | YES |
| All other parts | <100mm any axis | <100mm | YES |

---

## 4. Integration Verification (EA-28 Cross-Reference)

### Mechanical Interfaces

- [ ] Diff bar length 300mm fits body width (250mm pivot span + 25mm overhang each side)
- [ ] Rocker tube angles match `generate_rover_params.py` values
- [ ] All tube sockets accept 8mm rod with slide fit
- [ ] Horn link 20mm c/c matches servo horn + knuckle arm geometry
- [ ] Hard stop channels allow ±35° rotation
- [ ] All parts symmetric — no mirrored STLs needed (L/R flip on bed)

### Electrical Clearances

- [ ] Wire channel 8×6mm accommodates wire bundles at each joint
- [ ] Body cable exits (10×5mm × 6 slots) align with wire routing
- [ ] Electronics tray standoffs align with ESP32 + L298N mounting holes
- [ ] Kill switch bore (15mm) in rear body wall
- [ ] Battery tray recess fits 2S LiPo (86×34×19mm)

### Assembly Compatibility

- [ ] Body quadrant join seams align (M3 bolt holes match)
- [ ] Rocker pivot boss Z-height matches suspension geometry (Z=60mm)
- [ ] All M3 bolt holes clear heat-set insert positions
- [ ] Strain relief clips fit on wire bundles

---

## 5. Pre-First-Print Checklist

- [ ] CTC Bizer powered on and bed levelled
- [ ] PLA filament loaded (left extruder only)
- [ ] Right nozzle removed or parked (prevent scratching)
- [ ] Bed adhesion: glue stick or painter's tape applied
- [ ] Bed temp: 60°C
- [ ] Nozzle temp: 200-210°C (PLA)
- [ ] SD card available with x3g files
- [ ] GPX conversion tested: `gpx -m cr1d test.gcode test.x3g`
- [ ] Cura profile set for CTC Bizer (0.4mm nozzle, 0.2mm layer)
- [ ] First print: calibration test card (verify dimensional accuracy)
- [ ] Second print: bearing test piece (verify 608ZZ press-fit)
- [ ] Third print: tube socket test (verify 8mm rod slide fit)

---

## 6. Slicer Settings Reference

| Setting | Structural Parts | Body Panels | Small Parts |
|---|---|---|---|
| Layer height | 0.2mm | 0.2mm | 0.2mm |
| Nozzle | 0.4mm | 0.4mm | 0.4mm |
| Walls | 4-5 | 3-4 | 3 |
| Infill | 40-60% gyroid | 20% gyroid | 30% gyroid |
| Top/bottom layers | 4 | 4 | 4 |
| Supports | Off (most parts) | Off | Off |
| Bed temp | 60°C | 60°C | 60°C |
| Nozzle temp | 205°C ±5 | 205°C ±5 | 205°C ±5 |
| Speed | 40-50 mm/s | 40-50 mm/s | 40-50 mm/s |
| Brim | None | 5-8mm (body quads) | None |
| Retraction | 1-2mm @ 25mm/s | 1-2mm @ 25mm/s | 1-2mm @ 25mm/s |

**File workflow**: Fusion 360 → STL → Cura → gcode → `gpx -m cr1d input.gcode output.x3g` → SD card

---

## 7. Print Order (Recommended)

| Order | Part(s) | Qty | Est. Time | Purpose |
|---|---|-----|---|---|
| 1 | Calibration test card | 1 | 30 min | Verify printer accuracy |
| 2 | Bearing test piece | 1 | 15 min | Test 608ZZ press-fit |
| 3 | Tube socket test | 1 | 15 min | Test 8mm rod fit |
| 4 | 1× Wheel + 1× Steering bracket | 2 | 3 hrs | Test motor fit, bearing fit |
| 5 | 1× Servo mount + 1× Horn link | 2 | 45 min | Test SG90 fit, link geometry |
| 6 | Remaining 5× Wheels | 5 | 10 hrs | Batch overnight |
| 7 | 3× Steering brackets + 2× Fixed mounts | 5 | 4 hrs | Complete wheel mounts |
| 8 | 3× Servo mounts + 3× Horn links | 6 | 2 hrs | Complete steering |
| 9 | 4× Steering knuckles | 4 | 3 hrs | Test with bracket + bearing |
| 10 | Connectors (hub, bogie, front, middle, diff) | 11 | 8 hrs | Suspension connectors |
| 11 | 12× Cable clips | 12 | 2 hrs | Batch print |
| 12 | Electronics tray | 1 | 3 hrs | Wire test before body |
| 13 | Body quadrant FL | 1 | 8 hrs | Start body (overnight) |
| 14 | Body quadrant FR | 1 | 8 hrs | Overnight |
| 15 | Body quadrant RL | 1 | 10 hrs | Largest (overnight, trimmed) |
| 16 | Body quadrant RR | 1 | 10 hrs | Kill switch hole (overnight) |
| 17 | 4× Top deck tiles | 4 | 4 hrs | Cosmetic last |
| 18 | 10× Strain relief + fuse + switch | 12 | 2 hrs | Small parts, last |

**Total estimated print time: ~72 hours** (~3 days continuous or ~5 days practical)

---

## 8. Post-Print Assembly Verification

After all parts printed, before assembly:

- [ ] All bearing test piece fits verified (608ZZ, 8mm rod, tube socket)
- [ ] Heat-set inserts installed in all parts (~40 inserts at 170-180°C)
- [ ] 8mm steel rods cut to length (13 segments from 2× 1m rods)
- [ ] Rod ends deburred with file
- [ ] All parts labelled (L/R, FL/FR/RL/RR)
- [ ] Refer to EA-17 (Build Guide) for step-by-step assembly
- [ ] Refer to EA-28 (Integration) for interface verification

---

*Pre-Print Checklist v3.1 — 2026-03-25 (post CAD redesign, 29/29 STLs exported, EA-29)*

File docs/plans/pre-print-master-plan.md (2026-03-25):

# Pre-Print Master Engineering Plan

**Version:** 1.0
**Date:** 2026-03-24
**Status:** ACTIVE
**Author:** Claude Code + Charlie

## Purpose

Comprehensive engineering plan covering every step from requirements verification through to first drive. This plan was created after a full project deep-dive reading all 28 engineering analyses, 17 plan documents, 39 CAD scripts, 9 firmware modules, PWA, 7 ROS2 packages, CI pipeline, and tooling.

## Executive Summary

The Mars Rover Phase 1 prototype has exceptional documentation and software maturity (28 EAs, full firmware, PWA, 39 CAD scripts, CI/CD). However, **zero physical build work has started**. This plan identifies 25 issues found during the deep-dive and structures 8 phases of work from documentation cleanup through to first drive.

**Estimated timeline:** ~3-4 weeks (concurrent ordering + printing + testing)
**Estimated print time:** ~69 hours across 46 parts
**Estimated assembly time:** ~6-7 hours
**Budget:** ~GBP 153 (core) / ~GBP 244 (with tools)

---

## Issues Found During Deep-Dive

### Critical (Must Fix Before Printing)

| # | Category | Issue | Location | Fix |
|---|---|---|---|-----|
| 1 | Firmware | `FW_VERSION "0.2.0"` should be `"0.3.0"` | `firmware/esp32/config.h` | Update string |
| 2 | Firmware | Servo test constants mismatch (500/11.11 vs 544/10.31) | `firmware/tests/test_firmware_logic.py` | Sync to config.h |
| 3 | CAD | ~~Only 19 of 28 STLs exported~~ **FIXED: 29/29 STLs exported** (v1.0.0-cad-redesign) | `3d-print/` | ~~Re-run BatchExportAll~~ DONE |
| 4 | CAD | `printer_calibration.py` all zeroes, never imported | `cad/scripts/printer_calibration.py` | Calibrate printer, integrate |
| 5 | Electrical | L298N 78M05 rated 0.5A; 4x SG90 peak 2.6A | EA-19, BOM | Add XL4015 BEC to BOM |
| 6 | Electrical | L298N 5V logic, ESP32 3.3V output | EA-02, EA-19 | Add to bench test plan |

### Documentation (Stale References)

| # | File | Issue | Fix |
|---|---|---|-----|
| 7 | `docs/references/3d-printing-strategy.md` | References Ender 3 + PETG throughout | Mark superseded by EA-11 |
| 8 | `README.md` | Says "22 engineering analyses" | Update to "25, EA-00 through EA-24" |
| 9 | `docs/plans/design-methodology.md` | References "220x220mm for Ender 3" | Update to CTC Bizer 225x145mm |
| 10 | `docs/plans/fusion360-mcp-setup.md` | References Ender 3 + PETG | Update to CTC Bizer + PLA |
| 11 | `docs/plans/backup-strategy.md` | Wrong script path `scripts/backup.bat` | Update to `tools/backup.bat` |

### Phase 2 (Log as GitHub Issues, Don't Block Print)

| # | Package | Issue |
|---|---|---|
| 12 | rover_navigation | `ekf.yaml` config file missing (nav.launch.py references it) |
| 13 | rover_navigation | ackermann_controller `wheel_diameter_mm` defaults 120mm, should be 80mm |
| 14 | rover_hardware | Joint names in uart_bridge don't match URDF joint names |
| 15 | rover_navigation | No Nav2 lifecycle node bringup in nav.launch.py |
| 16 | rover_navigation | No SLAM node despite `use_slam` argument |
| 17 | rover_bringup | No simulation launch file (garden.world references one) |
| 18 | rover_autonomy | Duplicate `behaviour_trees/` and `behavior_trees/` directories |
| 19 | rover_bringup | Stale `.urdf` alongside active `.urdf.xacro` |
| 20 | rover_teleop | WebSocket port 81 (ESP32) vs 8081 (Jetson) inconsistency |
| 21 | rover_hardware | Ultrasonic sensor frames not in URDF |
| 22 | rover_hardware | Missing `setup.py` for `rover_bringup` |
| 23 | rover_msgs | Camera stream port mismatch (PWA 8080 vs web_server 8080) |

### Design Observations (Not Bugs)

| # | Observation | Impact |
|---|---|---|
| 24 | CAD scripts don't import `generate_rover_params.py` at runtime | Values hardcoded in cm; parameter file is reference only |
| 25 | Parts are symmetric — no mirrored STLs needed | Simplifies print campaign |

---

## Phase 0: Documentation & Consistency Sweep

**Duration:** 1-2 hours (software work, no hardware)
**Gate:** All docs consistent, firmware compiles, all tests pass

### Tasks

- [x] **0.1** Update `firmware/esp32/config.h` `FW_VERSION` from `"0.2.0"` to `"0.3.0"` ✓
- [x] **0.2** Sync servo test constants in `firmware/tests/test_firmware_logic.py` with config.h values (544/10.31) ✓
- [x] **0.3** Update `README.md` status line: "25 engineering analyses, EA-00 through EA-24" ✓
- [x] **0.4** Update `docs/plans/design-methodology.md` printer reference: CTC Bizer 225x145mm ✓
- [x] **0.5** Update `docs/plans/fusion360-mcp-setup.md` printer reference: CTC Bizer + PLA ✓
- [x] **0.6** Update `docs/plans/backup-strategy.md` script path: `tools/backup.bat` ✓
- [x] **0.7** Add deprecation notice to `docs/references/3d-printing-strategy.md` → superseded by EA-11 ✓
- [x] **0.8** Run `/firmware-validate` — compile + 42 tests + lint ✓ (1045KB/79%, 53KB/16%, 42/42 pass, 0 lint)
- [ ] **0.9** Create GitHub issues for all 12 Phase 2 ROS2 issues (#12-23 above) — DEFERRED (no remote repo configured)
- [x] **0.10** Run backup to E: drive ✓

### Gate Review Checklist
- [x] `arduino-cli compile` succeeds (flash <80%, RAM <20%) ✓
- [x] All 42 firmware tests pass ✓
- [x] No stale Ender 3 / PETG references in active docs ✓
- [x] `FW_VERSION` matches CHANGELOG ✓

---

## Phase 1: Requirements Traceability Review

**Duration:** 1-2 hours (software work, no hardware)
**Gate:** All requirements traced, BOM verified, power question resolved

### Tasks

- [x] **1.1** Walk through EA-22 functional requirements (FR-01 to FR-10) ✓ 9/10 fully traced, FR-10 orphan (no drop test proc)
- [x] **1.2** Walk through EA-22 dimensional requirements (DIM-01 to DIM-11) ✓ DIM-10/DIM-11 fixed (120→180mm, 80→90mm)
- [x] **1.3** Walk through EA-22 electrical requirements (ELEC-01 to ELEC-10) ✓ ELEC-04 (fuse) and ELEC-10 (ADC cap) gaps fixed in BOM
- [x] **1.4** Cross-check learning objectives ✓ LEARN-04/09/11 orphan (acceptable for prototype)
- [x] **1.5** Run BOM check ✓ 10 discrepancies found, 8 fixed (wall thickness, weights, fuse, cap, resistor, connector)
- [x] **1.6** Run wiring check ✓ 17 items checked, 9 discrepancies fixed (LEDC channels, wire gauges, connector type, resistor, pin names)
- [x] **1.7** **DECISION: Servo power** ✓ XL4015 BEC already in BOM (confirmed present)
- [x] **1.8** **DECISION: L298N 3.3V** ✓ Added as Phase 6 bench test item (test before committing)
- [x] **1.9** Update BOM and shopping list ✓ Fuse added, cap count 6→7, resistor 220→330, XT60 standardised, weights updated
- [x] **1.10** Requirements traceability ✓ 79% fully traced (31/43), 7% partial, 5% fixed mismatches, 16% orphan (acceptable)

### Additional Fixes Applied During Phase 1
- EA-09: Fixed LEDC Ch6/Ch7→Ch4/Ch5 for servo FL/FR, GPIO3 stale motor ref→spare, "Power button"→"E-stop"
- EA-23: Wire gauges reconciled (battery 18→14 AWG, distribution 20→16 AWG, motors 24→20 AWG), XT30→XT60
- EA-19: Spare pin count 5→6, ESP32 power wire 18→22 AWG
- EA-17, EA-06: XT30→XT60
- Signal wiring diagram: LED resistor 220R→330R
- Shopping list: XT60 standardised, resistor 220→330 ohm

### Gate Review Checklist
- [x] Every FR has firmware implementation identified ✓ (FR-10 orphan test logged)
- [x] Every DIM has CAD script identified ✓ (DIM-10/DIM-11 corrected)
- [x] Every ELEC has BOM line item identified ✓ (fuse + ADC cap added)
- [x] BEC already in BOM ✓ (confirmed)
- [x] BOM costs updated ✓
- [x] Orphan requirements documented ✓ (acceptable for learning prototype)

---

## Phase 2: CAD Final Verification & STL Export

**Duration:** 1-2 hours (requires Fusion 360 running)
**Gate:** All 29 STLs exported, dimensions verified, bed fit confirmed — **PASSED (v1.0.0-cad-redesign)**

### Tasks

- [x] **2.1** Run `/cad-audit` on all scripts — final consistency check ✓ 16 PASS, 1 FAIL (servo_mount wall), 0 stale values
- [x] **2.2** Deploy all scripts to Fusion 360 Scripts directory ✓ 3 fixed scripts deployed (body_quadrant, servo_mount, batch_export_all)
- [x] **2.3** Run BatchExportAll in Fusion 360 (via `/fusion-export`) ✓ 22/22 components, 0 errors, 48s
- [x] **2.4** Verify 29 STL files exist in `3d-print/` subdirectories ✓ 29/29 exported (full CAD redesign, v1.0.0-cad-redesign)
- [x] **2.5** Check body quadrant dimensions ≤225×145mm via `get_stl_info` ✓ RL/RR now 140×220mm (PASS)
- [x] **2.6** Check top deck exports are 4 separate tiles (each >5KB) ✓ FL 44KB, FR 106KB, RL 106KB, RR 60KB
- [x] **2.7** Check rover_tire.stl exists (even though CTC Bizer can't print TPU) ✓ 93KB
- [x] **2.8** Run `/preflight` on body_quadrant_rl (largest part, tightest bed fit) ✓ PASS — 140×220×80mm fits flat (5mm clearance each axis), ~8.5h, ~31g PLA, 40% gyroid, supports for pivot bosses
- [x] **2.9** Run `/preflight` on steering_bracket (tightest tolerance — 3.9mm bearing wall) ✓ PASS — 35×30×40mm, ~4.5h, ~26g PLA, 65% infill, 0.16mm layers, 5 perimeters, no supports, ream bearing bore post-print
- [x] **2.10** Run `/preflight` on rocker_arm_front (longest part) ✓ PASS — 30×195×15mm, ~4.5h, ~11g PLA, 50% gyroid, 4 perimeters, no supports, 195mm along 225mm bed axis
- [x] **2.11** Generate STL dimension verification table (bounding box vs expected) ✓ All 24 STLs verified post-fix
- [x] **2.12** Run backup to E: drive ✓

### Fixes Applied During Phase 2 (CAD Audit)
- **servo_mount.py**: BRACKET_W 15→18mm (wall around servo 1.4→2.9mm, meets 2.5mm minimum)
- **body_quadrant.py**: Trim extrude direction fixed (True→False, trim was cutting into empty space)
  - Bug: RL/RR rear quadrants measured 140×235mm, exceeding 225mm bed by 10mm
  - Root cause: Rocker pivot boss at Y seam protrudes 15mm, trim cut went wrong direction
  - After fix: RL/RR should be ~140×220mm (fits 145×225mm bed)
- **generate_rover_params.py**: body.wall_thickness 3→4mm (matches CAD scripts post-enhancement)

### STL Dimension Verification (post-fix, 24 files)
| Part | Dimensions (mm) | Bed Fit (225×145×150) | Size | Notes |
|---|---|---|---|---|
| bearing_test_piece | 30×30×10 | PASS | 30KB | Pre-existing |
| calibration_test_card | 80×30×5 | PASS | 266KB | |
| rover_wheel | 80×80×35 | PASS | 93KB | |
| rover_tire | 86×86×35 | PASS | 93KB | TPU — CTC can't print, Phase 2 |
| steering_bracket | 35×30×40 | PASS | 65KB | |
| fixed_wheel_mount | 25×25×30 | PASS | 35KB | |
| servo_mount | **40×18×25** | PASS | 63KB | **Fixed** (was 15mm wide) |
| bogie_arm | 30×180×12 | PASS | 29KB | |
| rocker_arm_front | 30×195×15 | PASS | 68KB | 195mm < 225mm bed |
| rocker_arm_rear | 30×118×15 | PASS | 64KB | |
| diff_bar_adapter | 30×30×20 | PASS | 74KB | |
| body_quadrant_fl | 130×220×80 | PASS | 95KB | 5mm X clearance |
| body_quadrant_fr | 130×220×80 | PASS | 95KB | 5mm X clearance |
| body_quadrant_rl | **140×220×80** | **PASS** | 117KB | **Fixed!** Was 235mm |
| body_quadrant_rr | **140×220×80** | **PASS** | 117KB | **Fixed!** Was 235mm |
| top_deck_fl | 130×220×11 | PASS | 44KB | |
| top_deck_fr | 130×220×11 | PASS | 106KB | |
| top_deck_rl | 130×220×11 | PASS | 106KB | |
| top_deck_rr | 130×220×11 | PASS | 60KB | |
| electronics_tray | 120×180×18 | PASS | 242KB | |
| strain_relief_clip | 18×10×12 | PASS | 30KB | |
| fuse_holder_bracket | 15×40×12 | PASS | 44KB | |
| switch_mount_plate | 30×30×5 | PASS | 30KB | |

### Gate Review Checklist
- [x] 24 STL files present (22 batch + bearing_test_piece + old unsplit top_deck) ✓
- [x] All body quadrants fit CTC Bizer bed (≤225×145mm) ✓ RL/RR fixed: 140×220mm
- [x] All parts fit bed height (≤150mm) ✓ Tallest: body quadrants at 80mm
- [x] Rocker arm halves each ≤225mm longest axis ✓ (195mm and 118mm)
- [x] No zero-size or corrupt STLs ✓ All 24 have >28KB and valid geometry
- [x] Batch export log shows 0 errors ✓ 22/22 components, 0 errors, 48s
- [x] Preflight checks on 3 critical parts ✓ (body_quadrant_rl, steering_bracket, rocker_arm_front — all GO)

---

## Phase 3: Printer Setup & Calibration

**Duration:** 1-2 days (physical work)
**Gate:** CTC Bizer calibrated, bearing test piece validates 608ZZ press-fit

### Prerequisites
- PLA filament on hand (order in Phase 4.1 if not already available)
- Digital calipers (±0.02mm)
- CTC Bizer powered and accessible

### Tasks

- [ ] **3.1** Follow `docs/plans/ctc-bizer-guide.md` initial setup checklist:
  - Mechanical inspection (belts, rods, linear bearings, pulleys)
  - Clean/replace nozzle (cold pull if clogged)
  - Right extruder: park or remove (raise 1-2mm above left)
  - Verify heated bed reaches 60°C uniformly
- [ ] **3.2** Bed levelling (4-corner paper test + centre check)
- [ ] **3.3** Load PLA filament (left extruder only)
- [ ] **3.4** Test extrusion: 100mm filament feed, verify actual = expected ±2mm
- [ ] **3.5** **Print #1: Calibration test card** (`calibration/calibration_test_card.stl`, ~30 min)
  - Measure all 7 test holes with calipers
  - Measure bearing counterbore (22.15mm target)
  - Record actual vs expected for each feature
- [ ] **3.6** **Print #2: 20mm XYZ calibration cube** (~20 min)
  - Measure X, Y, Z dimensions
  - Calculate scaling errors per axis
- [ ] **3.7** Update `cad/scripts/printer_calibration.py` with measured correction values:
  - `HOLE_DIAMETER_ERROR_MM`
  - `OUTER_DIMENSION_ERROR_MM`
  - `XY_ERROR_PER_100MM`
  - `Z_ERROR_PER_10MM`
  - `FIRST_LAYER_SPREAD_MM`
- [ ] **3.8** **Print #3: Bearing test piece** (`calibration/bearing_test_piece.stl`, ~20 min)
  - Test 608ZZ bearing press-fit
  - Target: snug push-fit, no rattle, no hammer needed
  - If too tight: increase bore by 0.05mm, reprint
  - If too loose: decrease bore by 0.05mm, reprint
  - Iterate until fit is correct (max 3 iterations)
- [ ] **3.9** Record validated bearing seat dimension (the golden number for this printer)
- [ ] **3.10** Log all calibration prints with `/print-log`
- [ ] **3.11** If calibration corrections are significant (>0.1mm), consider updating CAD scripts to compensate

### Gate Review Checklist
- [ ] CTC Bizer mechanically sound and printing clean layers
- [ ] Calibration card hole measurements recorded
- [ ] XYZ cube within ±0.2mm on all axes
- [ ] 608ZZ bearing fits bearing test piece correctly
- [ ] `printer_calibration.py` updated with real values
- [ ] Bearing seat "golden dimension" documented

---

## Phase 4: Parts Ordering

**Duration:** 1-2 weeks (delivery time)
**Gate:** All Phase 1 components on hand

### Ordering Strategy (per EA-17)

Order in batches to start printing while waiting for later deliveries:

- [ ] **4.1** — **Order 1: Filament** (order immediately, ~GBP 30)
  - 2× 1kg PLA spools (white or grey, 1.75mm)
  - Bed adhesion aids (glue stick or painter's tape)
- [ ] **4.2** — **Order 2: Electronics** (order week 1, ~GBP 45)
  - 1× ESP32-S3 DevKitC-1 N16R8
  - 2× L298N dual H-bridge driver
  - 6× N20 6V 100RPM geared motor
  - 4× SG90 micro servo
  - 1× XL4015 5V 3A buck converter (BEC for servo power)
  - 1× Tactile button (E-stop)
  - 1× Status LED (any colour)
  - 6× 100nF ceramic capacitors (motor noise suppression)
  - 1× 100nF ceramic capacitor (ADC filter)
  - Resistors: 1× 10k, 1× 4.7k (battery voltage divider)
  - Dupont jumper wires (M-F, F-F assortment)
  - Mini breadboard
- [ ] **4.3** — **Order 3: Mechanical** (order week 1-2, ~GBP 35)
  - 9× 608ZZ bearings (8×22×7mm) + 3 spares = buy 12
  - 1× 8mm steel rod, 350mm length (cut to 300mm)
  - M3 fasteners: 30× M3×12mm socket head, 20× M3 nuts, 50× M3 washers
  - M8 fasteners: 2× M8×60mm bolts, 4× M8 nuts, 8× M8 washers
  - M2 fasteners: 8× M2×10mm (servo mounting)
  - M3 heat-set inserts: 50× (M3, 5.7mm OD, 4.8mm hole, 5.5mm depth)
  - O-rings: 18× 70mm ID × 3mm cross-section (if not using TPU tires)
  - 3mm dowel pins × 8 (body alignment)
- [ ] **4.4** — **Order 4: Power & Safety** (order week 2, ~GBP 25)
  - 1× 2S LiPo 2200mAh 7.4V (XT30 or XT60 connector)
  - 2× XT30 connectors (male + female pair)
  - 1× ATC/ATO blade fuse holder + 5A blade fuse
  - 1× Panel-mount toggle switch (kill switch, ≥5A rated)
  - Wire: 2m 18AWG, 3m 22AWG, 5m 24AWG, 3m 26AWG
  - Heat shrink tubing assortment
  - LiPo balance charger (if not already owned)
- [ ] **4.5** Track deliveries, run `/bom-check` as items arrive

### Gate Review Checklist
- [ ] All 4 orders placed
- [ ] Filament arrived and loaded
- [ ] All electronics verified (ESP32 powers on, motors spin, servos move)
- [ ] All bearings checked (spin freely, correct size)
- [ ] Steel rod correct diameter (8mm ±0.05mm)
- [ ] All fasteners correct size and quantity
- [ ] Battery charges and holds voltage

---

## Phase 5: Print Campaign

**Duration:** ~10 days (~69 hours print time)
**Gate:** All 46 parts printed, test-fitted, and logged

### Print Order (optimised for progressive test-fitting)

Run `/preflight <part>` before each print. Run `/print-log <part>` after each print.

| Step | Part | Qty | Est. Time | Slicer Settings | Test Gate |
|---|---|-----|---|---|---|
| 1 | Bearing test piece | 1+ | 20 min | 4 walls, 50%, 0.2mm | 608ZZ press-fit |
| 2 | Calibration test card | 1 | 30 min | 4 walls, 50%, 0.2mm | Hole measurements |
| 3 | Rover wheel | 6 | 6 hrs | 4 walls, 50% gyroid | D-shaft bore, hub fit |
| 4 | Bogie arm | 2 | 2 hrs | 4 walls, 50% gyroid | Bearing seat, N20 clip, pivot bore |
| 5 | Rocker arm front | 2 | 2 hrs | 4 walls, 50% gyroid | Half-lap joint, bearing seat |
| 6 | Rocker arm rear | 2 | 2 hrs | 4 walls, 50% gyroid | Half-lap joint mates with front |
| 7 | Diff bar adapter | 3 | 1.5 hrs | 4 walls, 60% infill | 8mm rod bore, bearing seat |
| 8 | Steering bracket | 4 | 3 hrs | **5 walls**, **60% gyroid** | Bearing seat, N20 clip, M3 inserts |
| 9 | Fixed wheel mount | 2 | 1 hr | 4 walls, 50% gyroid | N20 clip, M3 inserts |
| 10 | Servo mount | 4 | 2 hrs | 4 walls, 50% gyroid | SG90 pocket fit |
| 11 | Body quadrant FL | 1 | 8 hrs | 4 walls, 20% gyroid | Tongue/groove, bearing seat, arm mount bosses |
| 12 | Body quadrant FR | 1 | 8 hrs | 4 walls, 20% gyroid | Tongue/groove, bearing seat |
| 13 | Body quadrant RL | 1 | 8 hrs | 4 walls, 20% gyroid | Tongue/groove, diff mount, **bed fit ≤225×145** |
| 14 | Body quadrant RR | 1 | 8 hrs | 4 walls, 20% gyroid | Kill switch hole, diff mount, **bed fit ≤225×145** |
| 15 | Top deck tiles | 4 | 4 hrs | 3 walls, 20% grid, **brim** | Snap clips, panel lines |
| 16 | Electronics tray | 1 | 3 hrs | 3 walls, 30% gyroid | ESP32 standoffs, L298N standoffs, battery cradle |
| 17 | Strain relief clips | 10 | 2 hrs | 3 walls, 50% infill | U-channel fits 4× 22AWG wires |
| 18 | Fuse holder bracket | 1 | 30 min | 3 walls, 40% infill | Fuse holder fits channel |
| 19 | Switch mount plate | 1 | 20 min | 4 walls, 60% infill | 15mm bore fits toggle switch |

**Total: 46 parts, ~69 hours**

### Slicer Workflow (per part)
1. Open STL in Cura
2. Apply settings from table above
3. Verify orientation (flat face down unless noted)
4. Check estimated time and filament usage
5. Slice → export gcode
6. Convert: `gpx -m cr1d input.gcode output.x3g`
7. Copy x3g to SD card
8. Print
9. Measure critical dimensions with calipers
10. Test-fit hardware (bearing, motor, servo as applicable)
11. Log with `/print-log`

### Progressive Test-Fitting Schedule
After printing each group, test-fit before continuing:
- After wheels (step 3): Test N20 D-shaft fit, O-ring groove fit
- After bogies (step 4): Assemble wheel → bogie with bearing
- After rockers (steps 5-6): Join halves, test pivot range
- After diff adapters (step 7): Test 8mm rod fit + bearing
- After steering (steps 8-10): Full corner assembly (bracket + servo + mount + wheel)
- After body (steps 11-14): Join quadrants, test rocker pivot fit
- After internals (steps 16-19): Dry-fit electronics tray in body

### Gate Review Checklist
- [ ] All 46 parts printed
- [ ] All bearing seats tested with 608ZZ
- [ ] All N20 clips tested with motor
- [ ] All SG90 pockets tested with servo
- [ ] All M3 heat-set inserts installed cleanly
- [ ] Rocker arm halves join correctly
- [ ] Body quadrants join with minimal gap
- [ ] Total PLA usage ≤2kg
- [ ] All prints logged with `/print-log`

---

## Phase 6: Electronics Bench Test

**Duration:** 2-4 hours (before mechanical assembly)
**Gate:** All electronics verified individually on bench

### Prerequisites
- ESP32-S3 and all electronics from Order 2
- USB cable for programming
- Multimeter
- Breadboard + jumper wires

### Tasks

- [ ] **6.1** Flash firmware to ESP32-S3 via USB:
  ```
  arduino-cli compile --fqbn esp32:esp32:esp32s3 firmware/esp32/
  arduino-cli upload --fqbn esp32:esp32:esp32s3 -p COMx firmware/esp32/
  ```
- [ ] **6.2** Verify WiFi connects (check serial monitor for IP address)
- [ ] **6.3** Load PWA in phone browser → verify all tabs render
- [ ] **6.4** **L298N 3.3V logic test** (CRITICAL):
  - Connect 1× L298N to ESP32 (ENA + IN1 + IN2)
  - Connect 1× N20 motor
  - Apply 7.4V from bench supply or charged LiPo
  - Verify motor spins forward and reverse at multiple speeds
  - If L298N doesn't respond to 3.3V: add 74HCT245 level shifter to BOM
- [ ] **6.5** Test all 4 motor channels (one at a time)
- [ ] **6.6** Test all 4 SG90 servos (verify centre, sweep range, trim via PWA)
- [ ] **6.7** Test XL4015 BEC: input 7.4V → output 5.00V ±0.1V, verify under 4-servo load
- [ ] **6.8** Verify battery ADC reading (compare ESP32 reported voltage vs multimeter)
- [ ] **6.9** Verify E-stop button response (<100ms, check via serial monitor)
- [ ] **6.10** Test WebSocket command → motor response → telemetry round-trip
- [ ] **6.11** Test OTA update (upload via WiFi)

### Gate Review Checklist
- [ ] ESP32-S3 connects to WiFi reliably
- [ ] PWA loads and displays correctly on phone
- [ ] L298N responds to 3.3V logic (or level shifter solution identified)
- [ ] All 6 motors spin at correct speed and direction
- [ ] All 4 servos centre correctly and reach ±35°
- [ ] Battery voltage reads within ±0.1V of multimeter
- [ ] E-stop halts motors within 100ms
- [ ] OTA update works
- [ ] XL4015 BEC provides stable 5V under servo load

---

## Phase 7: Mechanical Assembly

**Duration:** 6-7 hours
**Gate:** Rover fully assembled, all joints move freely

### Assembly Sequence (per `docs/plans/assembly-reference.md`)

- [ ] **7.1** Stage 1 — Part preparation:
  - Install all M3 heat-set inserts (soldering iron at 170-180°C for PLA)
  - Cut 8mm steel rod to 300mm
  - Deburr all printed parts
- [ ] **7.2** Stage 2 — Wheel sub-assemblies (×6):
  - Press 608ZZ bearing into wheel hub
  - Insert N20 motor into clip
  - Secure with M2 grub screw (if needed)
  - Attach O-rings to wheel grooves (if not using TPU tires)
- [ ] **7.3** Stage 3 — Bogie arms (×2):
  - Press 608ZZ bearing into central pivot
  - Attach middle wheel assembly (fixed mount + motor + wheel)
  - Attach rear wheel assembly (steering bracket + servo + motor + wheel)
- [ ] **7.4** Stage 4 — Steering assemblies (×4):
  - Mount SG90 servo into servo mount
  - Attach servo mount to steering bracket
  - Connect servo horn to steering bracket pivot
- [ ] **7.5** Stage 5 — Front wheel assemblies:
  - Attach front steering bracket + servo + motor + wheel to rocker arm front half
- [ ] **7.6** Stage 6 — Rocker-bogie suspension (×2):
  - Join rocker arm halves (half-lap joint, 2× M3 bolts)
  - Attach bogie arm to rocker arm rear half via pivot bearing
  - Verify articulation range: rocker ±25°, bogie ±20°
- [ ] **7.7** Stage 7 — Differential bar:
  - Press diff bar adapters onto 8mm rod at correct spacing
  - Press 608ZZ bearings into adapters
  - Verify differential mechanism (one rocker up → other down)
- [ ] **7.8** Stage 8 — Body frame:
  - Join 4 body quadrants with M3×12 bolts + heat-set inserts
  - Install alignment dowel pins
  - Verify tongue-and-groove seams align
  - Insert rocker pivots into body bearing seats
  - Attach differential bar to body
  - Verify all 6 wheels touch ground on flat surface
- [ ] **7.9** Stage 9 — Electronics and wiring:
  - Mount electronics tray inside body
  - Mount ESP32-S3 on standoffs
  - Mount 2× L298N on standoffs
  - Mount XL4015 BEC
  - Mount battery in cradle with strap
  - Wire per EA-23 wire harness specification (58 wires)
  - Install strain relief clips at pivot points
  - Install fuse holder and kill switch on RR quadrant
  - Route wires through arm channels with 50mm slack at pivots
  - Install top deck tiles

### Gate Review Checklist
- [ ] All 6 wheels spin freely
- [ ] All 4 steering servos move full range
- [ ] Rocker-bogie articulates correctly (push one side, other lifts)
- [ ] Differential bar moves freely
- [ ] All 6 wheels maintain ground contact on flat surface
- [ ] Body quadrants securely joined (no wobble)
- [ ] Electronics securely mounted
- [ ] All wires routed with no pinch points at pivots
- [ ] Kill switch disconnects power
- [ ] Total weight ≤1.5kg

---

## Phase 8: Integration Test & Acceptance

**Duration:** 2-4 hours
**Gate:** All EA-21 "Must" acceptance criteria met

### Pre-Power Safety Checks (per EA-19)
- [ ] **8.1** Visual inspection: no exposed conductors, no wire pinch points
- [ ] **8.2** Continuity check: VCC to GND should show high resistance (no shorts)
- [ ] **8.3** Voltage check: battery voltage within range (7.0-8.4V)
- [ ] **8.4** Fuse installed (5A blade)
- [ ] **8.5** Kill switch in OFF position

### First Power-On
- [ ] **8.6** Turn kill switch ON, verify power LED illuminates
- [ ] **8.7** Check serial monitor for boot sequence (WiFi connect, firmware version)
- [ ] **8.8** Connect phone to PWA, verify telemetry displays
- [ ] **8.9** Check battery voltage reading matches multimeter ±0.2V

### Motor Test
- [ ] **8.10** ARM the rover via PWA
- [ ] **8.11** Test each direction: forward, reverse, left, right
- [ ] **8.12** Verify all 6 wheels spin correct direction
- [ ] **8.13** If any motor reversed: swap IN1/IN2 wires for that channel

### Steering Test
- [ ] **8.14** Test Ackermann mode: left turn, right turn
- [ ] **8.15** Test point turn mode: clockwise, anticlockwise
- [ ] **8.16** Test crab walk mode: left, right
- [ ] **8.17** Calibrate servo trims via PWA settings (all wheels straight when centred)

### Acceptance Tests (per EA-21)

| Test ID | Requirement | Target | Method |
|---|---|---|---|
| PR-01 | Max speed | ≥0.2 m/s | Measure 5m timed run |
| PR-02 | Runtime | ≥30 min | Continuous driving test |
| PR-03 | Payload | 500g on top deck | Place weighted object |
| PR-04 | Obstacle | 20mm climb | Place obstacle in path |
| PR-05 | Slope | 15° grade | Use ramp or incline |
| PR-06 | Straight line | <100mm drift/5m | Measure deviation |
| PR-07 | Latency | <200ms command→action | Stopwatch test |
| PR-08 | WiFi range | ≥15m | Distance test outdoors |
| PR-09 | Weight | ≤1.5kg | Kitchen scale |
| PR-10 | Noise | <60dB at 1m | Phone dB meter app |

### Data Capture
- [ ] **8.18** Fill in `docs/plans/prototype-data-capture.md` with all measurements
- [ ] **8.19** Record all 12 learning objectives (LEARN-01 to LEARN-12)
- [ ] **8.20** Document any failures or issues in failure log section
- [ ] **8.21** Take photos/video of first drive
- [ ] **8.22** Update `docs/plans/future-design-improvements.md` Phase 1 Outcome columns

### Final Checklist
- [ ] All "Must" FRs met (FR-01 to FR-10)
- [ ] ≥8 of 12 PRs met
- [ ] All 12 learning objectives recorded
- [ ] 10+ min WiFi-controlled drive completed
- [ ] Disassembly/reassembly in <30 min demonstrated
- [ ] All data captured and documented
- [ ] Backup run to D: and E: drives
- [ ] Celebratory first outdoor drive

---

## Risk Register (Phase 1 Build-Specific)

| ID | Risk | Likelihood | Impact | Mitigation |
|----|---|---|---|---|
| R-01 | CTC Bizer can't achieve bearing tolerance | Medium | High | Bearing test piece iteration; worst case: drill out with 22mm bit |
| R-02 | L298N doesn't respond to 3.3V logic | Low | High | Bench test early (Phase 6.4); fallback: 74HCT245 level shifter (~$1) |
| R-03 | PLA parts too weak for assembly loads | Low | Medium | 4+ walls, 50%+ infill on structural; handle with care |
| R-04 | Body quadrants don't fit CTC Bizer bed | Low | High | Pre-verified in CAD at 220×130mm; margin 5mm each axis |
| R-05 | N20 motors insufficient torque | Low | Medium | Phase 1 is 1.25kg, N20 stall torque ~10 kg-cm; learning objective |
| R-06 | SG90 servos too weak for steering | Medium | Medium | Only 1.25kg vehicle; upgrade to MG996R in Phase 2 |
| R-07 | Battery runtime <30 min | Low | Low | 2200mAh at ~2A = ~65 min theoretical; learning objective |
| R-08 | WiFi range <15m | Medium | Low | ESP32-S3 has decent WiFi; test outdoors; external antenna in Phase 2 |
| R-09 | Rocker arm half-lap joint weak | Medium | Medium | 30mm overlap + 2× M3 bolts; reinforce with epoxy if needed |
| R-10 | Total weight exceeds 1.5kg | Low | Low | PLA estimate 1024g + ~226g electronics/battery = ~1.25kg |

---

## Quick Reference: Skills & Tools to Use at Each Phase

| Phase | Skills & Tools |
|---|---|
| 0 | `/firmware-validate`, `/simplify`, `github` MCP (create issues) |
| 1 | `/bom-check`, `/wiring-check`, `/tolerance-calc`, `math` MCP |
| 2 | `/cad-audit`, `/fusion-export`, `/preflight`, `3dprint` MCP (`get_stl_info`) |
| 3 | `/print-log`, `/tolerance-calc`, `3dprint` MCP (`get_stl_info`, `generate_stl_visualization`) |
| 4 | `/bom-check`, `jlcpcb` MCP (component search) |
| 5 | `/preflight`, `/print-log`, `/assembly-order`, `3dprint` MCP (slice, visualize) |
| 6 | `/firmware-validate`, `/esp32-deploy`, `/wiring-check`, `arduino-esp-helper` skill |
| 7 | `/assembly-order`, `/tolerance-calc`, `/wiring-check` |
| 8 | `/project-dashboard`, `/session-handoff`, `mermaid` MCP (results diagrams) |

---

## Version History

| Version | Date | Changes |
|---|---|---|
| 1.0 | 2026-03-24 | Initial plan after full project deep-dive |

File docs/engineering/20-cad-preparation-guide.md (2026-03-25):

# EA-20: CAD Preparation Guide for Fusion 360

**Document**: EA-20
**Date**: 2026-03-15
**Purpose**: Provide a complete reference for modelling the 0.4-scale Phase 1 prototype rover in Fusion 360, including assembly hierarchy, master dimensions, critical geometry, hardware cutouts, print orientation, and design-for-assembly guidance.
**Depends on**: EA-01 (Suspension), EA-08 (Phase 1 Spec), EA-10 (Ackermann Steering), EA-11 (3D Printing Strategy)

---

## 1. Assembly Structure

### 1.1 Top-Down Assembly Hierarchy

Model the rover as a single Fusion 360 Design with the following component tree. Use top-down modelling: create the skeleton sketch in the top-level component, then derive geometry into child components via projected references.

```
ROVER_P1_040  (root assembly)
  +-- BODY
  |     +-- BODY_FRONT_LEFT
  |     +-- BODY_FRONT_RIGHT
  |     +-- BODY_REAR_LEFT
  |     +-- BODY_REAR_RIGHT
  |     +-- TOP_DECK_COVER
  |     +-- ELECTRONICS_TRAY
  +-- SUSPENSION_LEFT
  |     +-- ROCKER_ARM_LEFT
  |     +-- BOGIE_ARM_LEFT
  +-- SUSPENSION_RIGHT
  |     +-- ROCKER_ARM_RIGHT
  |     +-- BOGIE_ARM_RIGHT
  +-- DIFFERENTIAL
  |     +-- DIFF_BAR_ROD
  |     +-- DIFF_ADAPTER_LEFT
  |     +-- DIFF_ADAPTER_CENTRE
  |     +-- DIFF_ADAPTER_RIGHT
  +-- STEERING_FL
  |     +-- STEERING_BRACKET_FL
  |     +-- SERVO_SG90_FL
  +-- STEERING_FR
  |     +-- STEERING_BRACKET_FR
  |     +-- SERVO_SG90_FR
  +-- STEERING_RL
  |     +-- STEERING_BRACKET_RL
  |     +-- SERVO_SG90_RL
  +-- STEERING_RR
  |     +-- STEERING_BRACKET_RR
  |     +-- SERVO_SG90_RR
  +-- FIXED_MOUNT_ML
  +-- FIXED_MOUNT_MR
  +-- WHEEL_FL
  +-- WHEEL_FR
  +-- WHEEL_ML
  +-- WHEEL_MR
  +-- WHEEL_RL
  +-- WHEEL_RR
  +-- MOTOR_N20_x6  (reusable component, 6 instances)
  +-- BEARING_608ZZ  (reusable component, 9 instances)
  +-- FASTENERS  (folder of reusable bolts/nuts)
```

### 1.2 Component Naming Convention

```
<SYSTEM>_<PART>_<SIDE/POSITION>_<VERSION>

Examples:
  ROCKER_ARM_LEFT_v1
  STEERING_BRACKET_FL_v2
  WHEEL_GENERIC_v1  (instanced 6 times)
  BEARING_608ZZ_v1  (instanced 9 times)
```

- Use UPPER_SNAKE_CASE for component names.
- Suffix with `_v1`, `_v2` etc. when iterating designs.
- Side labels: LEFT / RIGHT for suspension, FL / FR / ML / MR / RL / RR for wheel-corner parts.
- Fasteners and hardware: prefix with `HW_` (e.g., `HW_M8x40_BOLT`).

### 1.3 Coordinate System

**Origin**: Centre of the differential bar, at the body's mid-length, mid-width, and ground level (Z = 0 is ground plane).

| Axis | Direction | Positive Convention |
|---|---|---|
| X | Left-right | Positive = right (viewed from behind) |
| Y | Front-back | Positive = forward |
| Z | Up-down | Positive = up |

Key reference planes:
- **XZ plane (Y = 0)**: Middle axle line (ML/MR wheels)
- **YZ plane (X = 0)**: Rover centre line (symmetry plane)
- **XY plane (Z = 0)**: Ground plane

All dimensions below are in the rover coordinate system at 0.4 scale unless otherwise noted.

---

## 2. Master Dimensions Table

All values are Phase 1 (0.4 scale) in millimetres.

### 2.1 Overall Dimensions

| Part | Dimension | Value (mm) | Tolerance | Notes |
|---|---|---|---|---|
| Body (outer) | Length (Y) | 440 | +/-1.0 | 4 quadrant prints on 225x145mm bed (Y split at Y=0) |
| Body (outer) | Width (X) | 260 | +/-1.0 | 4 quadrant prints on 225x145mm bed (X split at X=0) |
| Body (outer) | Height (Z) | 80 | +/-0.5 | Open-top box frame |
| Body (inner cavity) | Length | 434 | derived | 3mm walls each end |
| Body (inner cavity) | Width | 254 | derived | 3mm walls each side |
| Body (inner cavity) | Height | 74 | derived | 3mm floor, open top |
| Body wall thickness | Outer walls | 3.0 | +/-0.2 | 4 perimeters at 0.4mm nozzle |
| Body wall thickness | Internal ribs | 2.0 | +/-0.2 | |
| Top deck cover | L x W x H | 440 x 260 x 2 | +/-0.5 | Optional, cosmetic |
| Wheelbase (per side) | Front-to-rear axle (Y) | 360 | +/-1.0 | W1-to-W3 ground spacing |
| Track width | Wheel centre-to-centre (X) | 280 | +/-1.0 | Left to right |
| Ground clearance | Under body frame (Z) | 60 | +/-2.0 | |
| Driving height | Ground to top of body | 420 | reference | Without mast (no mast in Phase 1) |

### 2.2 Rocker Arms (x2)

| Part | Dimension | Value (mm) | Tolerance | Notes |
|---|---|---|---|---|
| Rocker arm | Total length | 180 | +/-0.5 | Body pivot to front wheel axle |
| Rocker arm | Cross-section outer | 20 x 15 | +/-0.3 | Rectangular tube |
| Rocker arm | Wall thickness | 3.0 | +/-0.2 | |
| Rocker arm | Body pivot bore | 8.0 | H7 (+0.000/+0.015) | For 608ZZ inner race |
| Rocker arm | Body pivot boss OD | 22.1 | +0.0/-0.1 | Press-fit for 608ZZ outer race |
| Rocker arm | Bogie pivot bore | 8.0 | H7 | For 608ZZ inner race |
| Rocker arm | Bogie pivot boss OD | 22.1 | +0.0/-0.1 | Press-fit for 608ZZ |
| Rocker arm | Front motor mount face | 25mm PCD | +/-0.2 | 4x M3 holes on pitch circle |
| Rocker arm | Weight (each) | ~35g | estimate | PLA, 50% gyroid infill |

### 2.3 Bogie Arms (x2)

| Part | Dimension | Value (mm) | Tolerance | Notes |
|---|---|---|---|---|
| Bogie arm | Total length | 180 | +/-0.5 | W2 axle to W3 axle (full scale 450mm x 0.4) |
| Bogie arm | Pivot to each wheel | 90 | +/-0.3 | Symmetric |
| Bogie arm | Cross-section outer | 15 x 12 | +/-0.3 | Rectangular tube |
| Bogie arm | Wall thickness | 2.5 | +/-0.2 | |
| Bogie arm | Pivot bore | 8.0 | H7 | For 608ZZ |
| Bogie arm | Motor mount faces | 4x M3 | +/-0.2 | Each end |
| Bogie arm | Weight (each) | ~20g | estimate | |

### 2.4 Differential Bar

| Part | Dimension | Value (mm) | Tolerance | Notes |
|---|---|---|---|---|
| Differential bar | Rod length | 300 | +/-1.0 | 250mm pivot span + 25mm overhang each side |
| Differential bar | Rod OD | 8.0 | h9 | Steel rod, fits 608ZZ bore |
| Differential bar | Rod ID (if tube) | N/A | N/A | Solid 8mm steel rod recommended |
| Diff adapter (x3) | Tube OD | 12.0 | +/-0.3 | Printed end caps |
| Diff adapter | Tube ID | 8.0 | +0.05/-0.00 | Press-fit onto rod |
| Diff adapter | Bearing seat OD | 22.1 | +0.0/-0.1 | For 608ZZ |
| Diff adapter | Bearing seat depth | 7.2 | +/-0.1 | Full 608ZZ width + 0.2mm |
| Diff adapter | Weight (each) | ~5g | estimate | |

### 2.5 Wheels (x6)

| Part | Dimension | Value (mm) | Tolerance | Notes |
|---|---|---|---|---|
| Wheel | Outer diameter | 80 | +/-0.5 | Including tread grousers |
| Wheel | Width | 32 | +/-0.3 | Tread included |
| Wheel | Hub bore (D-shaft) | 3.1 | +0.05/-0.00 | 0.1mm clearance for N20 3mm D-shaft |
| Wheel | D-flat depth | 0.5 | +/-0.1 | |
| Wheel | Hub boss OD | 10 | +/-0.3 | |
| Wheel | Hub boss length | 8 | +/-0.3 | Full shaft engagement |
| Wheel | Grousers (count) | 12 | -- | Chevron pattern |
| Wheel | Grouser depth | 3.0 | +/-0.2 | |
| Wheel | Grouser width (base) | 3.0 | +/-0.2 | |
| Wheel | Spoke count | 6 | -- | With flex zones |
| Wheel | M2 grub screw hole | 2.0 | +/-0.1 | Perpendicular to shaft |
| Wheel | Weight (each) | ~25g | estimate | |

### 2.6 Steering Assembly (x4 corners)

| Part | Dimension | Value (mm) | Tolerance | Notes |
|---|---|---|---|---|
| Steering bracket | L x W x H | 35 x 25 x 40 | +/-0.3 | Rotates on 608ZZ |
| Steering bracket | Bearing seat OD | 22.1 | +0.0/-0.1 | Top face |
| Steering bracket | Bearing seat depth | 7.2 | +/-0.1 | |
| Steering bracket | Pivot bore | 8.0 | H7 | M8 bolt through |
| Steering bracket | N20 clip inner W | 12.2 | +0.1/-0.0 | 0.2mm clearance |
| Steering bracket | N20 clip inner H | 10.2 | +0.1/-0.0 | |
| Steering bracket | Clip wall thickness | 2.0 | +/-0.2 | |
| Steering bracket | Snap tab protrusion | 0.5 | +/-0.1 | |
| Steering bracket | Motor shaft exit hole | 4.0 | +/-0.2 | |
| Steering bracket | Servo horn length | 15 | +/-0.3 | SG90 horn |
| Steering bracket | Weight (each) | ~12g | estimate | |
| Steering | Max angle | +/-35 deg | -- | Limited by arm geometry |
| Steering | Pivot-to-wheel-centre | 20 | +/-0.5 | Vertical offset |
| Steering | Wheel-to-arm clearance | >= 5 | minimum | At full lock (35 deg) |

### 2.7 Fixed Wheel Mounts (x2, middle wheels)

| Part | Dimension | Value (mm) | Tolerance | Notes |
|---|---|---|---|---|
| Fixed mount | L x W x H | 25 x 25 x 30 | +/-0.3 | |
| Fixed mount | N20 motor clip | Same as steering bracket clip | | |
| Fixed mount | M3 bolt holes to bogie | 2x M3 clearance (3.4mm) | +/-0.1 | |
| Fixed mount | Weight (each) | ~8g | estimate | |

### 2.8 N20 Gearmotor (x6)

| Part | Dimension | Value (mm) | Tolerance | Notes |
|---|---|---|---|---|
| N20 motor | Body dimensions | 12 x 10 x 15 | reference | Motor can only |
| N20 motor | Gearbox length | 9 | reference | Total length = 24mm |
| N20 motor | Total length | 24 | reference | Motor can (15mm) + gearbox (9mm) |
| N20 motor | Shaft diameter | 3.0 (D-shaft) | reference | |
| N20 motor | Shaft protrusion | 10 | reference | |
| N20 motor | Mounting screws | 2x M2, 9mm centres | reference | |
| N20 motor | Weight (each) | ~10g | reference | |

### 2.9 608ZZ Bearing (x9)

| Part | Dimension | Value (mm) | Tolerance | Notes |
|---|---|---|---|---|
| 608ZZ | Inner diameter (bore) | 8.0 | -- | Standard |
| 608ZZ | Outer diameter | 22.0 | -- | Standard |
| 608ZZ | Width | 7.0 | -- | Standard |
| 608ZZ | Seal type | ZZ | -- | Metal shields both sides |
| 608ZZ | Weight (each) | 12g | -- | |

### 2.10 Body Features

| Feature | Dimension | Value (mm) | Tolerance | Notes |
|---|---|---|---|---|
| Rocker pivot holes | Bore | 8.0 | H7 | At Y=0, Z=+60, X=+/-125 |
| Rocker pivot holes | Boss OD | 22.1 | +0.0/-0.1 | 608ZZ seat |
| Battery tray recess | L x W x H | 86 x 34 x 25 | +/-1.0 | Floor centre, fits 2S 2200mAh LiPo |
| Cable routing channels | Cross-section | 10 x 10 | +/-0.5 | Grooves in floor |
| Switch mount | Diameter | 15 | +/-0.3 | Rear wall, power switch |
| Ventilation slots | Width x count | 3mm x 5 | +/-0.2 | Each side wall |
| ESP32 standoffs | 4x M3 | PCD per DevKit | +/-0.3 | 62.7x25.4mm board |
| L298N standoffs | 4x M3 | 37mm PCD | +/-0.3 | 43x43mm board, 2 sets |
| Body join seams | Bolts | 12x M3x12 | -- | 6 per seam (Y=0 and X=0), see Section 5.3 |
| Top deck clips | Count | 8 | -- | Snap clips along edges |

### 2.11 Electronics Components (mounting reference)

| Component | Dimensions (mm) | Mount Pattern |
|---|---|---|
| ESP32-S3 DevKit | 62.7 x 25.4 | 4x M3 standoffs |
| L298N driver (x2) | 43 x 43 x 27 | 4x M3 standoffs, 37mm PCD |
| 2S LiPo 2200mAh | 86 x 34 x 19 | Battery tray + Velcro strap |
| Power switch | 15mm panel mount | Rear wall hole |
| Mini breadboard | 47 x 35 | Adhesive back |

---

## 3. Critical Geometry

### 3.1 Rocker Pivot Point Location

The rocker pivots are the primary connection between the body and suspension.

| Parameter | Value | Reference |
|---|---|---|
| X position | +/-125mm from centre line | Inset from body side wall (260/2 - 5mm clearance) |
| Y position | 0mm (middle axle line) | Aligns with XZ plane |
| Z position | +60mm above ground | Body floor at Z=60, pivots at floor level |
| Pivot axis | Parallel to Y axis | Rocker swings in the XZ plane (roll motion) |

### 3.2 Bogie Pivot Point Location

Each bogie pivots at the rear end of the rocker arm.

| Parameter | Value | Reference |
|---|---|---|
| Relative to rocker body pivot | 180mm along rocker arm | At the rocker's far end from the front wheel |
| X offset from rocker pivot | 0mm | Same X as rocker (coplanar) |
| Pivot axis | Parallel to X axis | Bogie swings in the YZ plane (pitch motion) |

At neutral suspension (flat ground):
- Bogie pivot Y = 0mm (same Y as rocker pivot, middle axle line)
- Bogie pivot Z = approximately +40mm (depends on arm angle at rest)

### 3.3 Differential Bar Pivot and Linkage Points

```
Front View (looking forward, +Y into page):

         [Centre Pivot]
         X=0, Y=0, Z=+60
        /                 \
  100mm                    100mm
      /                       \
[Left End]              [Right End]
X=-100, Z=+60           X=+100, Z=+60
    |                        |
  [Left Rocker]        [Right Rocker]
  Pivot                  Pivot
  X=-125                 X=+125
```

| Point | X (mm) | Y (mm) | Z (mm) | Notes |
|---|---|---|---|---|
| Diff bar centre pivot | 0 | 0 | +60 | Attached to body frame |
| Diff bar left end | -100 | 0 | +60 | Connected to left rocker via linkage |
| Diff bar right end | +100 | 0 | +60 | Connected to right rocker via linkage |
| Left rocker pivot | -125 | 0 | +60 | On body frame |
| Right rocker pivot | +125 | 0 | +60 | On body frame |

The 25mm gap between diff bar end (X=+/-100) and rocker pivot (X=+/-125) is bridged by the differential adapter linkage.

**Differential bar angular range**: +/-20 degrees from horizontal.

### 3.4 Steering Axis Locations (4 Corners)

Steering pivots are vertical axes (parallel to Z) at each steered wheel position.

| Wheel | X (mm) | Y (mm) | Z (mm) | Notes |
|---|---|---|---|---|
| FL steering pivot | -140 | +180 | ~+40 | On rocker arm front end |
| FR steering pivot | +140 | +180 | ~+40 | On rocker arm front end |
| RL steering pivot | -140 | -180 | ~+40 | On bogie arm rear end |
| RR steering pivot | +140 | -180 | ~+40 | On bogie arm rear end |
| ML (fixed, no steering) | -140 | 0 | ~+40 | Direct mount on bogie |
| MR (fixed, no steering) | +140 | 0 | ~+40 | Direct mount on bogie |

### 3.5 Wheel Axis Offsets from Steering Axis

The wheel rotates about the motor shaft axis (horizontal, parallel to X). This axis is offset below the steering pivot axis (vertical, parallel to Z).

| Parameter | Value (mm) | Notes |
|---|---|---|
| Vertical offset (steering pivot to wheel centre) | 20 | Wheel axle is 20mm below steering pivot |
| Lateral offset (steering axis to wheel centre plane) | 0 | Wheel centre is directly below steering axis |
| Steering bracket height accounts for this offset | 40 | 608ZZ at top, motor clip at bottom |

### 3.6 Wheel Positions at Neutral (Flat Ground)

| Wheel | Label | X (mm) | Y (mm) | Z (mm) | Notes |
|---|---|---|---|---|---|
| Front-left | W1 / FL | -140 | +180 | +40 | Centre of wheel (radius = 40mm, ground at Z=0) |
| Middle-left | W2 / ML | -140 | 0 | +40 | |
| Rear-left | W3 / RL | -140 | -180 | +40 | |
| Rear-right | W4 / RR | +140 | -180 | +40 | |
| Middle-right | W5 / MR | +140 | 0 | +40 | |
| Front-right | W6 / FR | +140 | +180 | +40 | |

### 3.7 Suspension Articulation Range

| Motion | Range | Limit |
|---|---|---|
| Rocker swing (roll) | +/-25 degrees | Mechanical stop on body |
| Bogie swing (pitch) | +/-20 degrees | Limited by arm geometry |
| Differential bar twist | +/-20 degrees | One rocker up = other down |
| Body pitch halving | Diff bar averages left/right | Body tilts half the angle of either side |

---

## 4. Bearing & Hardware Cutouts

### 4.1 608ZZ Bearing Press-Fit Holes

All 9 bearing locations use the same pocket geometry.

| Feature | Dimension (mm) | Notes |
|---|---|---|
| Bearing seat bore diameter | 22.1 | 0.1mm oversize for PLA press fit (PLA shrinks ~0.2-0.4%) |
| Bearing seat depth | 7.2 | Full 608ZZ width (7mm) + 0.2mm clearance |
| Shaft through-hole | 8.0 | Bearing inner race sits on shaft |
| Retention feature | Printed lip (0.5mm) or snap ring groove | Prevents bearing walking out |
| Chamfer at entry | 0.3mm x 45 deg | Guides bearing during installation |

**Critical note**: Test-print a bearing test block before printing structural parts. Adjust the 22.1mm bore +/-0.1mm based on your printer's actual dimensional accuracy. Target: bearing presses in firmly by hand, no hammer needed.

### 4.2 M3 Heat-Set Insert Holes

Per EA-11 specifications, adapted for PLA.

| Feature | Dimension (mm) | Notes |
|---|---|---|
| Insert type | M3 x 5.7mm OD x 4.6mm length | Brass, knurled |
| Hole diameter | 4.8 | Undersized vs 5.7mm OD; plastic flows around knurls |
| Hole depth | 5.5 | 1mm deeper than insert for full seating |
| Wall thickness around hole | >= 2.4 | 3 perimeters at 0.4mm line width minimum |
| Chamfer at top | 0.5mm x 45 deg | Guides insert during installation |
| Bottom | Flat (blind hole) | Unless through-hole specifically needed |
| Installation temperature | 170-180 deg C | For PLA (lower than PETG to prevent warping) |

**Quantity needed**: 46 inserts across all parts (12 body join seams, remainder for standoffs, brackets).

### 4.3 8mm Shaft Holes

For M8 bolts and the differential bar steel rod.

| Feature | Dimension (mm) | Notes |
|---|---|---|
| Shaft hole diameter | 8.0 | H7 tolerance: +0.000 / +0.015mm |
| M8 bolt clearance hole | 8.4 | Where bolt passes through (not bearing seat) |
| Washer recess (optional) | 16mm dia x 1.5mm deep | For M8 washer counterbore |

### 4.4 SG90 Servo Mounting Pattern

| Feature | Dimension (mm) | Notes |
|---|---|---|
| Servo body | 22.2 x 11.8 x 22.7 (without tabs) | Standard SG90 |
| Servo body + tabs | 32.2 x 11.8 x 22.7 | Tabs add 5mm each side |
| Mounting tab holes | 2x M2 clearance (2.2mm) | One each side |
| Tab hole spacing | 27.5mm centre-to-centre | Across the servo body |
| Tab hole to servo centre | 5mm from body edge | |
| Shaft centre from edge | 6mm from tab edge | Offset from centre |
| Horn arm length | 15mm | Single-arm horn |
| Horn spline | 21T, 4.8mm OD | Standard micro servo spline |
| Servo pocket depth | 12mm minimum | Clears body below tabs |

### 4.5 N20 Motor Mount Pattern

Using snap-fit clip design (not screws).

| Feature | Dimension (mm) | Notes |
|---|---|---|
| Motor body envelope | 12 x 10 x 24 (with gearbox) | Total L includes gearbox |
| Clip inner width | 12.2 | 0.2mm clearance on motor body |
| Clip inner height | 10.2 | 0.2mm clearance |
| Clip wall thickness | 2.0 | Flex arms |
| Snap tab protrusion | 0.5 | Retains motor in clip |
| Shaft exit hole | 4.0 diameter | Centred on motor face |
| Alternative: M2 screw holes | 2x M2, 9mm centres | If clip proves unreliable |

---

## 5. Print Orientation & Segmentation

### 5.1 Print Orientation for Each Part

| Part | Print Orientation | Rationale | Support Needed |
|---|---|---|---|
| Body quadrants (x4) | Flat (XY plane, floor on bed) | Largest face down, structural floor; all quadrants ~220x130mm fit on 225x145mm bed | Minimal (teardrop pivot holes on inner quadrants) |
| Top deck cover | Flat (outer face on bed) | Best surface finish on visible side | None |
| Rocker arm (x2) | On side (longest axis horizontal) | Load axis along layer lines, not across | Minimal (teardrop bearing holes) |
| Bogie arm (x2) | On side | Same rationale as rocker | Minimal |
| Diff bar adapters (x3) | Upright (bearing seat on top) | Bearing bore prints as circle in XY | None |
| Wheels (x6) | Flat (tread face on bed, axle vertical) | Strongest axis is radial, smooth tread surface | None (design spokes for bridging) |
| Steering brackets (x4) | Upright (bearing seat on top, motor clip on bottom) | Bearing bore in XY, motor clip overhang manageable | Yes (motor clip overhang) |
| Fixed wheel mounts (x2) | Upright | Motor clip on bottom | Minimal |
| Bearing test piece | Any orientation matching target part | Validates bore dimensions | Minimal |

### 5.2 Segmentation Plan

The body exceeds the CTC 225×145mm bed in both axes. All other parts fit comfortably.

| Part | Full Size | Exceeds Bed? | Segments | Segment Size | Join Method |
|---|---|---|---|---|---|
| Body | 440 x 260 x 80 | Yes (both axes) | 4 quadrants (front-left, front-right, rear-left, rear-right) | All: ~220x130x80 | 12x M3x12 bolts + heat-set inserts + alignment features (see 5.3) |
| Rocker arm | 180mm long | No | 1 piece | Fits in 200mm axis | N/A |
| Bogie arm | 180mm long | No | 1 piece | Fits in 200mm axis | N/A |
| Diff bar | 300mm rod + adapters | No (adapters are small) | Rod + 3 printed adapters | Adapters ~20mm each | Steel rod core |
| Wheels | 80mm dia | No | 1 piece each | Fits easily | N/A |
| Steering brackets | 35 x 25 x 40 | No | 1 piece each | Small | N/A |
| Fixed mounts | 25 x 25 x 30 | No | 1 piece each | Small | N/A |

**Note on rocker arms**: At 180mm length, the rocker arm fits within the 225mm bed axis with comfortable margin. Orient the rocker arm along the longest bed axis.

**Note on bogie arms**: At 180mm length (full scale 450mm x 0.4), the bogie arm fits within the 225mm bed axis.

### 5.3 Body Join / Interlock Design

The body is split into 4 quadrants at two planes:
- **Y = 0** (front/rear split, at middle axle line)
- **X = 0** (left/right split at the rover centre line)

Split planes:
- **X = 0**: Left/right split (260mm / 2 = 130mm per side -- fits 145mm bed axis)
- **Y = 0**: Front/rear split at centre (440mm / 2 = 220mm per half -- fits 225mm bed axis)

All 4 quadrants are 220x130mm, which fits comfortably on the CTC Bizer 225x145mm bed without needing diagonal orientation or offset splits.

```
Top view of body quadrants:

              X = 0 (left/right split)
                |
    FRONT-LEFT  |  FRONT-RIGHT
    220x130mm   |  220x130mm
                |
  Y=0 ---------+--------- Y=0 (front/rear split, at centre)
                |
    REAR-LEFT   |  REAR-RIGHT
    220x130mm   |  220x130mm
                |
```

```
Cross-section at Y=0 seam (looking from side):

Front quadrant          Rear quadrant
+----------+  +  +----------+
|  +-[M3]--+--+--+-[insert]-+  |
|  |       | lip | |         |  |
|  +-------+ 10mm+-----------+  |
|          |    |              |
+----------+  +----------+

Same lip/bolt pattern applies to X=0 seam.
```

**Fasteners**:
- Y=0 seam (front/rear): 6x M3x12mm bolts (3 per side wall + 3 through floor)
- X=0 seam (left/right): 6x M3x12mm bolts (3 per front/rear wall + 3 through floor)
- Total: 12x M3x12mm bolts + 12x M3 heat-set inserts for body join

**Alignment features** (critical for 4-segment registration):
- **Dowel pin holes**: 4x 3mm steel dowel pins in the floor at each quadrant corner near the centre cross (+/-20mm from origin). Each pin bridges two adjacent quadrants for precise alignment.
- **Tongue-and-groove joints**: Along both seam lines, add a 2mm x 2mm tongue on one half and a matching 2.2mm x 2.2mm groove on the other. This prevents lateral sliding during assembly and adds shear strength.
- **Alignment tabs**: 2x 5mm wide x 10mm long x 3mm tall interlocking tabs at each seam midpoint, alternating male/female between adjacent quadrants. Provides positive location during bolt-up.

**Assembly order**: Start with rear-left quadrant. Add rear-right (align X=0 seam, insert dowels, bolt). Then add front-left to rear-left (align Y=0 seam). Finally add front-right, aligning both seams simultaneously.

### 5.4 Support Structure Requirements

| Part | Support Location | Support Type | Removal Notes |
|---|---|---|---|
| Body quadrants | Rocker pivot holes (horizontal cylinders, on inner quadrants only) | Use teardrop profile to avoid supports | Ream to round after printing |
| Rocker arm | Bearing boss holes | Teardrop profile | Ream with 22mm drill |
| Bogie arm | Bearing boss hole | Teardrop profile | Ream |
| Steering bracket | Motor clip overhang at bottom | Tree supports in slicer | Remove carefully |
| All other parts | None | Designed for supportless printing | N/A |

---

## 6. Design for Assembly

### 6.1 Assembly Sequence

Build from the inside out, bottom to top, one side then the other.

**Stage 1: Prepare Printed Parts**
1. Remove all support material
2. Ream all 608ZZ bearing seats with 22mm drill bit (test fit each bearing)
3. Ream all 8mm shaft holes
4. Ream all D-shaft bores in wheel hubs
5. Install all M3 heat-set inserts (soldering iron at 170-180 deg C, 3 seconds each)
6. Dry-fit all joints before adding fasteners

**Stage 2: Build Left Suspension**
1. Press 608ZZ into rocker arm body-pivot boss
2. Press 608ZZ into rocker arm bogie-pivot boss
3. Press 608ZZ into bogie arm rocker-pivot boss
4. Join rocker-to-bogie via M8 bolt + washers + nyloc nut (finger-tight, must rotate freely)
5. Mount steering bracket to rocker front end (608ZZ + M8 bolt)
6. Mount fixed motor bracket to bogie middle position
7. Mount steering bracket to bogie rear position

**Stage 3: Build Right Suspension**
8. Repeat steps 1-7 for right side

**Stage 4: Install Differential Bar**
9. Slide 8mm steel rod through centre adapter (with 608ZZ bearing, mounted in body frame)
10. Attach left end adapter to left rocker pivot linkage
11. Attach right end adapter to right rocker pivot linkage
12. Verify both rockers seesaw freely

**Stage 5: Mount Suspension to Body**
13. Join body quadrants: rear-left + rear-right first, then front-left + front-right, then front to rear (12x M3x12 + dowel pins + alignment tabs)
14. Insert M8 bolts through body rocker pivot holes
15. Slide on rocker arm bearings, add washers and nyloc nuts
16. Verify +/-25 deg rocker swing range

**Stage 6: Motors and Wheels**
17. Snap N20 motors into all 6 motor clips
18. Route motor wires through arms to body cavity
19. Press wheels onto 3mm D-shafts
20. Secure with M2 grub screws
21. Verify all 6 wheels spin freely

**Stage 7: Servos**
22. Mount SG90 servos in steering brackets (M2 screws)
23. Attach servo horns to steering pivot arms
24. Centre all servos (1500us PWM = straight ahead)
25. Verify +/-35 deg steering range without binding

**Stage 8: Electronics**
26. Mount ESP32-S3 on M3 standoffs
27. Mount L298N boards on M3 standoffs
28. Wire motors to L298N outputs
29. Wire L298N control pins to ESP32 GPIOs
30. Wire servo signals to ESP32 GPIOs (power from 5V rail)
31. Secure battery with Velcro strap in battery tray
32. Connect battery via power switch

### 6.2 Access Panel Locations

| Panel | Location | Purpose | Attachment |
|---|---|---|---|
| Top deck cover | Full top of body | Access all electronics | 8x snap clips (tool-free removal) |
| Battery access | Floor centre (flip rover) | Battery swap | Velcro strap release |
| Power switch | Rear wall | On/off without opening | 15mm panel mount switch |

### 6.3 Cable Routing Channel Dimensions

| Feature | Dimension (mm) | Notes |
|---|---|---|
| Floor channels | 10 x 10 cross-section | Grooves in body floor |
| Channel path | From each side wall to centre | Motor wires route inward to drivers |
| Servo wire entry | Through arm/bracket | 3-wire (signal/power/ground) per servo |
| Minimum bend radius | 15mm | For stranded wire harness |
| Wire exit from arm | 5mm diameter hole | At rocker pivot (allows arm rotation) |

### 6.4 Clearance Requirements

| Clearance | Minimum (mm) | Condition | Notes |
|---|---|---|---|
| Wheel to arm (steering) | 5 | At full lock (+/-35 deg) | Wheel rear edge swings 18.4mm at 35 deg |
| Wheel to body | 10 | At max suspension travel | Prevent rubbing |
| Rocker arm to body | 3 | At +/-25 deg swing | Side clearance |
| Bogie arm to rocker arm | 3 | At +/-20 deg swing | |
| Differential bar to body | 5 | At +/-20 deg twist | |
| Motor wires to moving parts | 5 | Throughout travel range | Prevent pinching |
| Steering bracket to arm end | 2 | All positions | Bearing width + washer stack |

---

## 7. Design Checklist

Complete each item before exporting STL files for printing.

### 7.1 Geometry Validation

- [ ] All 608ZZ bearing seats are 22.1mm OD x 7.2mm deep
- [ ] All 8mm shaft holes are correctly sized (H7 for bearing seats, 8.4mm for clearance)
- [ ] All M3 heat-set insert holes are 4.8mm diameter x 5.5mm deep with 0.5mm chamfer
- [ ] All M3 clearance holes are 3.4mm diameter
- [ ] N20 motor clip dimensions: 12.2mm x 10.2mm inner, 2mm walls
- [ ] D-shaft bore is 3.1mm with 0.5mm D-flat
- [ ] SG90 servo pocket and mounting holes match datasheet
- [ ] Body join seams (Y=0 and X=0) each have 10mm overlap lips, 6x M3 bolt positions, dowel pin holes, and tongue-and-groove joints
- [ ] Cable routing channels are at least 10mm x 10mm

### 7.2 Clearance & Motion

- [ ] Animate rocker swing +/-25 deg -- no collisions with body or diff bar
- [ ] Animate bogie swing +/-20 deg -- no collisions with rocker arm
- [ ] Animate diff bar +/-20 deg -- no collisions with body cavity
- [ ] Animate steering +/-35 deg -- wheel clears arm with >= 5mm gap
- [ ] Verify ground clearance >= 60mm at all articulation positions
- [ ] Verify wheel-to-body clearance at max suspension + max steering combined

### 7.3 Assembly Feasibility

- [ ] All fasteners are accessible with standard hex keys (2mm for M3, 5mm for M8)
- [ ] Heat-set inserts can be installed with straight soldering iron access
- [ ] Bearings can be pressed in without obstruction from adjacent features
- [ ] Motor clips allow motor insertion/removal (test with draft model)
- [ ] Servo can be installed/removed from bracket without disassembling other parts
- [ ] Battery tray allows battery insertion/removal with rover assembled
- [ ] Wire routing holes align between adjacent parts at all articulation angles

### 7.4 Print Readiness

- [ ] No part segment exceeds 140mm x 190mm x 150mm (CTC usable volume with margin)
- [ ] Print orientation is set per Section 5.1 table
- [ ] Horizontal bearing holes use teardrop profile (or supports are planned)
- [ ] Wall thickness around all inserts >= 2.4mm
- [ ] No unsupported overhangs > 45 deg (or supports planned)
- [ ] Bridges are <= 30mm span (or supports planned)
- [ ] Part has flat, stable surface on build plate (no rocking)
- [ ] Draft angle on snap-fit features >= 1 deg

### 7.5 Export

- [ ] Export each component as individual STL (not full assembly)
- [ ] Verify STL is watertight (no non-manifold edges) -- use Fusion 360 Mesh > Repair
- [ ] Filename matches component name: `ROCKER_ARM_LEFT_v1.stl`
- [ ] Include print orientation note in filename or companion text file
- [ ] Save Fusion 360 `.f3d` archive backup before exporting

---

*Document EA-20 v1.0 -- 2026-03-15*

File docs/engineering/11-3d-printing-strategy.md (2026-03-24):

# Engineering Analysis 11: 3D Printing Strategy

**Document**: EA-11
**Date**: 2026-03-15
**Purpose**: Define material selection, print settings, part segmentation, print orientation, heat-set insert specifications, and post-processing for all 3D printed rover components across all build phases.
**Depends on**: EA-01 (Suspension), EA-05 (Weight), EA-08 (Phase 1 Spec)
**See also**: `docs/references/3d-printing-strategy.md` and `docs/references/3d-printing-materials-research.md` — supplementary research with community project data, CNC Kitchen strength test numbers, and additional printing tips

---

## 1. Material Selection

### 1.1 Material Comparison for Rover Application

| Property | PLA | PETG | ABS | ASA | PA (Nylon) |
|---|-----|---|-----|-----|---|
| **Tensile strength** | 60 MPa | 50 MPa | 40 MPa | 45 MPa | 70 MPa |
| **Layer adhesion** | Good | Very good | Moderate | Moderate | Excellent |
| **Impact resistance** | Low (brittle) | High | High | High | Very high |
| **Heat resistance (HDT)** | 52°C | 70°C | 98°C | 98°C | 180°C |
| **UV resistance** | Poor | Moderate | Poor | **Excellent** | Good |
| **Moisture absorption** | Low | Low | Very low | Very low | **High** |
| **Outdoor durability** | 6-12 months | 1-3 years | 6-12 months (UV) | **3-5 years** | 2-4 years |
| **Print difficulty** | Easy | Easy | Moderate (warps) | Moderate (warps) | Hard (hygroscopic) |
| **Enclosure needed** | No | No | Yes | Yes | Yes |
| **Bed adhesion** | Good (60°C) | Good (75°C) | Needs glue (100°C) | Needs glue (100°C) | Needs glue (70°C) |
| **Cost (1kg spool)** | $18-22 | $20-25 | $18-22 | $25-30 | $35-50 |
| **Acetone smoothable** | No | No | **Yes** | **Yes** | No |
| **Food-safe (fridge)** | With coating | **PETG is food-safe** | No | No | No |

### 1.2 Material Recommendations by Phase

| Phase | Primary Material | Rationale |
|---|---|---|
| **Phase 1 (prototype)** | **PLA** | Low cost, easy to print on CTC Bizer (which only supports PLA), adequate strength for a 1.1 kg indoor prototype. Heat-set inserts work at 170-180°C. Phase 2 will upgrade to PETG/ASA for outdoor durability. |
| **Phase 2 (outdoor use)** | **ASA** for structural, **PETG** for body panels | ASA is the best outdoor material: excellent UV resistance, ABS-like properties without the brittleness. PETG for non-structural panels (food-safe for fridge area, easier to print). Will require a PETG/ASA-capable printer (not the CTC Bizer). |
| **Phase 3 (metal)** | **PETG/ASA** for retained plastic parts | Only camera housings, cable clips, and decorative elements remain plastic in Phase 3. |

### 1.3 Why PLA for Phase 1

PLA is the right choice for the Phase 1 indoor prototype:

1. **CTC Bizer compatibility**: The CTC Bizer only supports PLA reliably. No heated chamber, no all-metal hotend — PLA prints perfectly on this machine.
2. **Low cost**: PLA is the cheapest filament (~$18-22/kg). Phase 1 uses ~1 kg total, so <$25 in material.
3. **Easy to print**: PLA is the most forgiving material — minimal warping, no enclosure needed, prints at 200-210°C with 60°C bed and 100% fan.
4. **Adequate for indoor use**: At 1.1 kg total rover weight, PLA's 60 MPa tensile strength provides a 60x safety margin over the N20 motor loads. The prototype will operate indoors, so UV degradation and heat deflection (52°C) are not concerns.
5. **Heat-set inserts work well**: Brass inserts install cleanly in PLA at 170-180°C (lower than the 220°C used for PETG).
6. **Phase 2 upgrade path**: When the rover moves to full-scale outdoor operation, all structural parts will be reprinted in PETG/ASA on a more capable printer. PLA Phase 1 parts serve as proven templates.

**PLA limitations to be aware of**:
- Will soften above 52°C — do not leave in direct sun or a hot car
- Brittle under impact — handle with care, avoid drops
- Not UV-stable — prototype is for indoor/sheltered use only

### 1.4 Printer: CTC Bizer (MakerBot Replicator 1 Dual Clone)

| Specification | Value |
|---|---|
| **Model** | CTC 3D Bizer (MakerBot Replicator 1 Dual clone) |
| **Build volume** | 225 × 145 × 150mm |
| **Extruders** | Dual (use left nozzle only; park/remove right nozzle) |
| **Firmware** | MakerBot/Sailfish (not Marlin) |
| **File format** | **x3g** (NOT standard gcode) — requires GPX converter |
| **Heated bed** | Yes |
| **Material support** | PLA only (no all-metal hotend for PETG/ABS/ASA) |
| **Bed adhesion** | Heated bed 60°C + glue stick or painter's tape; brim for large parts |
| **Status** | Older machine, needs setup and calibration before first print |

**Material compatibility**:

| Material | CTC Bizer Compatible? | Notes |
|---|---|---|
| PLA | **Yes** — primary material | 200-210°C nozzle, 60°C bed |
| PETG | No | Requires all-metal hotend (PTFE tube degrades above 240°C) |
| ABS/ASA | No | Requires enclosed chamber + all-metal hotend |
| TPU | No | Requires direct drive extruder (CTC Bizer is Bowden-fed) |

**x3g file format workflow**:

The CTC Bizer uses x3g format (not standard gcode). The full workflow is:

```
Fusion 360 → STL → Cura (slice) → .gcode → GPX (convert) → .x3g → SD card → Print
```

GPX command: `gpx -m cr1d input.gcode output.x3g`
GPX v2.6.8 installed at `C:\Users\charl\bin\gpx.exe`, machine type `cr1d` (CTC Replicator 1 Dual).

**For Phase 2**: A PETG/ASA-capable printer will be needed (e.g., Bambu Lab A1, Prusa MK4, or similar). Budget ~$200-400 for a Phase 2 printer upgrade.

---

## 2. Print Settings by Part Category

### 2.1 Structural Parts (Rocker Arms, Bogie Arms, Motor Mounts)

These parts bear mechanical loads and must resist bending/shear forces.

| Setting | Value | Rationale |
|---|---|---|
| Material | PLA (Phase 1) / ASA (Phase 2) | PLA adequate for 1.1 kg indoor prototype; ASA for outdoor durability |
| Layer height | 0.2mm | Good strength, reasonable speed |
| Nozzle | 0.4mm standard | Default, widely available |
| Walls/perimeters | 4 (1.6mm wall thickness) | Primary load path is through walls |
| Top/bottom layers | 5 (1.0mm) | Prevents puncture and adds rigidity |
| Infill | 50% gyroid | High strength-to-weight ratio |
| Print speed | 40-50 mm/s | Slower for better layer adhesion |
| Temperature (PLA) | **200-210°C nozzle, 60°C bed** | Standard PLA on CTC Bizer |
| Temperature (ASA) | 250°C nozzle, 100°C bed | Requires enclosure (Phase 2 printer) |
| Cooling fan | **100% (PLA)**, 0% first layers (ASA) | PLA benefits from maximum cooling |
| Retraction | 5mm at 40mm/s (Bowden) | Prevents stringing |

### 2.2 Body Panels (Cosmetic + Light Structural)

Flat or curved panels that form the rover body shell. Phase 1 body is split into 4 quadrants (FL/FR/RL/RR), each 220x130mm.

| Setting | Value | Rationale |
|---|---|---|
| Material | PLA (Phase 1) / ASA (Phase 2) | PLA for indoor prototype; ASA for weather resistance |
| Layer height | 0.2mm | Good surface finish |
| Walls | 4 (1.6mm / 4mm wall for Phase 1 body quadrants) | Thicker walls for rigidity and panel line grooves |
| Top/bottom layers | 4 | Smooth surface |
| Infill | 15-20% gyroid | Panels don't bear heavy loads |
| Print speed | 50-60 mm/s | Faster for large flat parts |
| Temperature (PLA) | **200-210°C nozzle, 60°C bed** | Standard PLA |
| Cooling fan | **100%** | PLA benefits from maximum cooling |
| Notes | Print face-down for best top surface | Bed side = exterior surface |

### 2.3 Wheels

| Setting | Value | Rationale |
|---|---|---|
| Material | PLA (Phase 1 hub) | Adequate for indoor prototype; rigid PLA wheels with rubber O-ring traction bands |
| Layer height | 0.2mm | Smooth tread surface |
| Walls | 3 | Hub is reinforced by spokes |
| Infill | 25% gyroid | Lightweight but rigid |
| Print orientation | Flat (tread face on bed) | Strongest axis is radial |
| Temperature (PLA) | **200-210°C nozzle, 60°C bed** | Standard PLA |
| Cooling fan | **100%** | PLA benefits from maximum cooling |
| Notes | D-shaft bore may need reaming | Print slightly undersized, ream to fit |

### 2.4 Connectors & Brackets (Heat-Set Insert Parts)

Small parts that join extrusions or hold bearings.

| Setting | Value | Rationale |
|---|---|---|
| Material | PLA (Phase 1) / ASA (Phase 2) | PLA holds heat-set inserts well at 170-180°C |
| Layer height | 0.16mm | Better resolution for insert holes |
| Walls | 4-5 | Maximum wall around inserts |
| Infill | 60-80% | Dense for insert retention |
| Print speed | 35-40 mm/s | Precision over speed |
| Temperature (PLA) | **200-210°C nozzle, 60°C bed** | Standard PLA |
| Cooling fan | **100%** | PLA benefits from maximum cooling |
| Top/bottom layers | 5 | Strength |

---

## 3. Heat-Set Insert Specification

### 3.1 Insert Selection

| Parameter | Value |
|---|---|
| Size | M3 × 5.7mm (OD) × 4.6mm (length) |
| Material | Brass, knurled |
| Thread | M3 (0.5mm pitch) |
| Supplier | CNC Kitchen style / AliExpress bulk |
| Cost | ~$0.06 each |
| Pull-out strength (PLA) | 600-1,000N (per CNC Kitchen testing with proper hole sizing) |
| Torque resistance | ~2.5 N·m |

### 3.2 Hole Design for Inserts

| Feature | Dimension | Notes |
|---|---|---|
| Hole diameter | 4.8mm (general) | Slightly undersized vs insert OD (5.7mm) — plastic flows around knurls |
| Hole diameter (vertical insertion) | 4.2mm | Insert axis perpendicular to layers — tighter hole, knurls grip layer lines |
| Hole diameter (horizontal insertion) | 4.25mm | Insert axis parallel to layers — slightly larger to avoid pushing layers apart |
| Hole depth | 5.5mm | 1mm deeper than insert to allow full seating |
| Wall thickness around hole | ≥2.4mm (3 walls at 0.4mm line width) | Prevents blowout |
| Chamfer at top | 0.5mm × 45° | Guides insert during installation |
| Bottom | Flat (blind hole) | Don't use through-hole unless needed |

### 3.3 Installation Method

| Step | Detail |
|---|---|
| Tool | Soldering iron with M3 insert tip (or standard conical tip) |
| Temperature | **170-180°C for PLA** (lower than PETG's 220°C to avoid melting too much surrounding material), 230°C for ASA |
| Technique | Place insert on hole, press straight down with iron tip inside insert thread. Let the heat melt the surrounding plastic — do NOT force. Takes 2-3 seconds. |
| Depth | Flush with surface or 0.2mm below |
| Alignment | Press straight — crooked inserts compromise thread engagement |
| Cool time | 10 seconds before handling |
| Quality check | Thread an M3 bolt in/out — should go smooth with no binding |

### 3.4 Insert Orientation vs Print Layers

**Best**: Insert axis perpendicular to print layers (inserted from top or bottom face). The knurls grip into layer lines, maximising pull-out strength.

**Acceptable**: Insert axis parallel to layers (inserted from side). Slightly lower pull-out strength (~70% of perpendicular) because the knurls push layers apart rather than gripping into them.

**Rule**: Where possible, design parts so inserts go in perpendicular to layers. If this conflicts with the best print orientation for strength, prioritise the print orientation and accept slightly lower insert strength (still far exceeds our loads).

**Always print a test insert block first.** A small 30×30×15mm block with 2-3 insert holes lets you validate hole diameter, insertion depth, and pull-out strength before committing to a multi-hour structural print.

### 3.5 Slicer Tip: Local Infill Override

In Cura or PrusaSlicer, use **modifier meshes** to set 100% infill in a cylinder around each insert hole while keeping the rest of the part at normal infill (30-50%). This maximises insert retention without wasting filament on the entire part. Create a cylinder modifier (10mm OD × hole depth) centred on each insert location.

---

## 4. Part Segmentation Strategy

### 4.1 CTC Bizer Build Volume

| Dimension | Value | Usable (with margins) |
|---|---|---|
| X | 225mm | 215mm |
| Y | 145mm | 135mm |
| Z | 150mm | 140mm |

**Note**: The CTC Bizer bed (225x145mm) is narrower than common printers like the Ender 3 (220x220mm). The 145mm Y dimension is the primary constraint — all parts must fit within this. The 150mm Z height is also relatively limited.

### 4.2 Phase 1 Segmentation (0.4 Scale)

Body is 440mm × 260mm × 80mm — exceeds the 225×145mm CTC Bizer bed in both X and Y directions.

| Part | Full Dimension | Segments | Segment Size | Join Method |
|---|---|---|---|---|
| Body | 440×260×80 | **4 quadrants (FL/FR/RL/RR)** | **220×130×80 each** | M3 bolts + heat-set inserts at seams |
| Top deck | 440×260mm | **4 tiles (FL/FR/RL/RR)** | **220×130mm each** | Clips + alignment features |
| Rocker arm | 180mm long | 2 halves (front + rear) | ~90mm each | M3 bolts through overlap |
| Bogie arm | **180mm** long | 1 piece | Fits in 215mm | No segmentation |
| Diff bar | 300mm rod | 1 piece + rod | Adapters fit easily | Steel rod core |
| Wheels | 80mm dia | 1 piece each | Fits easily | No segmentation |
| Steering brackets | 35×25×40 | 1 piece each | Small | No segmentation |

**Total segments**: 4 (body quadrants) + 4 (top deck tiles) + 4 (rocker halves) + 2 bogies + 3 diff adapters + 6 wheels + 4 steering + 2 fixed mounts + 2 servo mounts + 1 electronics tray + 1 strain relief clip + 1 fuse holder + 1 switch mount = **~26 core parts** (see EA-08 and Phase 1 BOM for complete list with 46 total including hardware)

### 4.3 Phase 2 Segmentation (Full Scale)

Body is 1100mm × 650mm × 400mm — needs extensive segmentation.

| Part | Full Dimension | Segments | Join Method |
|---|---|---|---|
| Top deck | 1100×650mm | ~30 tiles (220×130mm each, 5×6 grid) | M3 inserts + alignment pins |
| Side panels | 1100×200mm | 5 per side (220×200mm each) | M3 inserts |
| Electronics bay floor | 650×440mm | 6 panels (220×220mm) | M3 inserts + 2020 extrusion ribs |
| Rocker arm shell | 450mm long | 2 halves (225mm each) | M3 bolts + internal aluminium rod |
| Bogie arm shell | 300mm long | 2 halves (150mm each) | M3 bolts + internal aluminium rod |
| Wheel | 200mm dia × 80mm | 2 halves (glued + bolted) | M3 through-bolts |
| Camera mast | 600mm tall × 60mm OD | 3 sections (200mm each) | Telescoping fit |
| Arm segments | ~150mm each | 1 piece each | Direct |
| Fridge housing | 200×150×200mm | 4 panels | M3 inserts |
| Camera mounts | <100mm each | 1 piece each | Direct |

**Total Phase 2 parts**: ~80-100 printed pieces.

### 4.4 Join Design for Segmented Parts

**Method 1: Bolt + Heat-Set Insert** (primary method)

```
Cross-section of body panel join:

Panel A                    Panel B
┌──────────┐  ┌──────────────┐
│  ┌─[M3]──┼──┼─[insert]─┐  │
│  │       ││  ││          │  │
│  └───────┼┘  └┼──────────┘  │
│          │    │              │
└──────────┘  └──────────────┘

Overlap lip: 10mm on each panel
Insert spacing: 40-60mm apart
```

**Method 2: Alignment Pin + Bolt** (for precision joints)

```
Alignment pin (3mm steel rod) ensures panels are flush:

Panel A:  ○ pin hole (3.1mm)    Panel B:  ○ pin hole (3.1mm)
          ● bolt hole                     ⊗ heat-set insert

Pin goes in first (aligns panels), then bolt tightens.
```

**Method 3: Dovetail** (for body panels that don't need disassembly)

```
Panel A              Panel B
┌─────────\    /─────────┐
│          \  /          │
│           \/           │
│           /\           │
│          /  \          │
└─────────/    \─────────┘

Print tolerance: 0.2mm gap for sliding fit
Secured with CA glue after assembly
```

---

## 5. Print Orientation Guidelines

### 5.1 General Principle

**Layers should be perpendicular to the primary load direction.** FDM parts are weakest in the Z-axis (layer adhesion) and strongest in X/Y (within layers).

### 5.2 Orientation by Part

| Part | Primary Load | Print Orientation | Support Needed |
|---|---|---|---|
| Rocker arm | Bending (vertical loads on wheels) | **On side** — longest axis horizontal, load direction along layer lines | Minimal — teardrop bearing holes |
| Bogie arm | Bending (vertical loads) | **On side** — same rationale | Minimal |
| Wheel hub | Radial (motor torque) | **Flat** — tread face on bed, layers stack along axle | None if designed with bridging |
| Body panels | Flat pressure | **Flat** — outer face on bed (best surface finish on bed side) | None |
| Steering bracket | Vertical load + torque | **Upright** — bearing seat on top | Yes — motor clip overhang |
| Connectors | Tension (bolt pull-out) | **Bolt axis perpendicular to bed** — inserts go in from top | None |
| Mast sections | Bending (wind, vibration) | **Upright** — layers wrap around circumference | None if round |

### 5.3 Rocker Arm Orientation Detail

```
WRONG — weak Z-axis takes the load:

   Bed
   ├───────────────────────────┤
   │  ████████████████████████ │ ← layers
   │  ████████████████████████ │
   │  ████████████████████████ │
   ├───────────────────────────┤
   Load applied here (down) → layers peel apart (delamination)

RIGHT — strong X-axis takes the load:

   Bed
   ├────────┤
   │ ██████ │ ← layers
   │ ██████ │
   │ ██████ │
   │ ██████ │
   │ ██████ │    Load applied here (left/right)
   │ ██████ │    → layers resist in shear (strong)
   │ ██████ │
   ├────────┤
```

### 5.4 Bearing Hole Orientation

Round holes printed horizontally (axis parallel to bed) tend to sag at the top due to gravity during bridging. Solutions:

1. **Teardrop profile**: Design the hole as a teardrop (point at top). The pointed top bridges cleanly. Ream to round after printing.

```
    /\         ← Point bridges cleanly
   /  \
  |    |       ← Circular lower portion
  |    |
   \  /
    \/
```

2. **Print with supports**: Less preferred — support material is hard to remove from inside a bearing seat.

3. **Print hole axis vertical**: If the part geometry allows, orient so the bearing bore is vertical. Circles print perfectly in XY.

---

## 6. Wheel Manufacturing

### 6.1 Phase 1 Wheels (80mm diameter)

**Design**: One-piece PLA wheel with spoke lightening holes, rim retention lips, and rubber O-ring traction bands (PLA is too rigid for integrated grousers to provide traction; O-rings provide grip on hard surfaces). Optional TPU tire if a compatible printer becomes available.

```
Cross-section:

    ┌─┐  ┌─┐  ┌─┐  ┌─┐  ┌─┐    ← Grousers (3mm deep, 3mm wide)
    │ │  │ │  │ │  │ │  │ │
────┘ └──┘ └──┘ └──┘ └──┘ └────  ← Tyre surface

    │←── 80mm diameter ──→│

    ┌───────[Hub]───────┐
    │    ┌───────────┐  │
    │    │   ┌───┐   │  │   ← 6 spokes connecting hub to rim
    │    │   │3mm│   │  │
    │    │   │ D │   │  │   ← D-shaft bore (3.1mm)
    │    │   └───┘   │  │
    │    └───────────┘  │
    └───────────────────┘
```

**Spoke pattern options**:
- **Straight radial spokes** (simplest): 6-8 rectangular spokes (4mm wide × 6mm tall). Prints flat with no supports. Adequate for Phase 1.
- **Curved/swept spokes** (recommended for Mars aesthetic): Spokes curve in one direction like a turbine. Curvature is in X/Y plane so prints without support. Better at absorbing lateral impacts. Looks like Curiosity/Perseverance wheels.

Grouser pattern: **Chevron** (V-shaped, point facing forward)
- 12 grousers evenly spaced (30° apart)
- 3mm depth, 3mm wide at base, 2mm wide at tip
- Chevron angle: 120° (60° from centre line)
- Good for grass (digs in for traction) and gravel (self-cleaning)

### 6.2 Phase 2 Wheels (200mm diameter)

**Design**: Two-piece construction — PETG hub + TPU tyre.

**Hub** (printed in two halves, bolted together around motor shaft):
- 6-spoke design with central D-shaft bore
- 4× M3 mounting bolts (through both halves)
- Outer rim: groove for TPU tyre retention

**TPU tyre** (printed as a flexible ring):
- Material: TPU 95A (Shore 95A hardness — semi-flexible)
- Width: 80mm
- Thickness: 8mm
- Chevron grousers: 5mm deep, 4mm wide
- Printed flat as a ring (180mm ID, 200mm OD)
- Stretches over hub rim — interference fit (0.3mm Phase 1, 0.5mm Phase 2) + optional CA glue

**TPU printing notes**:
- TPU requires direct drive extruder (Bowden tube has too much flex)
- CTC Bizer cannot print TPU (Bowden-fed). Phase 1 uses rigid PLA wheels with rubber O-ring traction bands instead.
- Phase 2 TPU tire option: 86mm OD, 70mm bore, 32mm width, 48 radial tread ribs (see `cad/scripts/rover_tire.py`)
- Alternative for any phase: use rubber O-rings (70mm ID x 3mm cross-section) in rim grooves for traction

### 6.3 Motor Shaft Interface

| Phase | Motor | Shaft | Interface |
|---|---|---|---|
| Phase 1 | N20 | 3mm D-shaft | D-bore in hub + M2 grub screw |
| Phase 2 | Chihai 37mm | 6mm D-shaft | D-bore in hub + M3 grub screw |

**D-shaft bore design**:
- Print bore 0.1mm oversized (3.1mm / 6.1mm)
- D-flat: 0.5mm deep (Phase 1) / 1.0mm deep (Phase 2)
- Grub screw hole: perpendicular to shaft, tapped M2/M3
- Bore length: ≥8mm (Phase 1) / ≥15mm (Phase 2) for adequate engagement

---

## 7. Post-Processing

### 7.1 Standard Post-Processing

| Step | Method | Purpose |
|---|---|---|
| 1 | Remove supports | Clean up overhangs |
| 2 | Trim stringing | Hot air gun or lighter (quick pass) |
| 3 | Ream bearing holes | 22mm drill bit by hand | Ensure 608ZZ fits |
| 4 | Ream shaft bores | Appropriate drill bit | Ensure motor shaft fits |
| 5 | Install heat-set inserts | Soldering iron at 170-180°C (PLA) / 220°C (PETG) | Before assembly |
| 6 | Test-fit all joints | Dry assembly | Catch issues before final assembly |

### 7.2 UV Protection (Phase 2 Outdoor Parts)

PETG parts used outdoors should be protected from UV:

| Method | Durability | Effort | Cost | Notes |
|---|---|---|---|---|
| UV-resistant spray paint | 2-3 years | Low | $10 | Rustoleum 2× spray, 2 coats |
| Automotive clear coat | 3-5 years | Low | $8 | 2K clear coat, very durable |
| Epoxy coating | 5+ years | Medium | $20 | XTC-3D or similar, fills layer lines too |
| Print in ASA instead | 5+ years | None | $5 extra/kg | Best solution — UV-resistant material |

**Recommendation**: Print structural parts in ASA for inherent UV resistance. For PETG body panels, apply 2 coats of automotive clear coat spray — quick, cheap, effective.

**4-step spray paint process (best results for PETG panels)**:
1. **Sand**: 220 grit over entire surface for mechanical adhesion
2. **Primer**: Rust-Oleum 2X Ultra Cover Primer — 2 coats, 15min between coats
3. **Color**: 2-3 thin coats of spray paint (any Rust-Oleum 2X color), 10min between coats. Thin coats prevent drips and build even coverage.
4. **Clear coat**: Rust-Oleum Crystal Clear matte or satin — 2 coats, 20min between coats. **This is the primary UV barrier.** Without clear coat, the color will fade and the plastic underneath degrades.
5. Total cost: ~£15-20 for entire rover

**Important notes**:
- XTC-3D epoxy fills layer lines and gives a smooth finish but is NOT UV stable — must apply clear coat over it or it will yellow and crack within months outdoors.
- ASA can be chemically smoothed with MEK (methyl ethyl ketone) but MEK is hazardous (respiratory and skin irritant, flammable). Spray paint + clear coat is a safer alternative that also provides UV protection and colour in one process.

### 7.4 Phase 2 Structural Reinforcement

For high-stress parts at full scale (16.7 kg rover weight):

| Method | Application | Difficulty | When to Use |
|---|---|---|---|
| Carbon fiber strips (1mm × 10mm pultruded) | Epoxy-bonded to rocker/bogie arm surfaces | Easy — glue flat strips along arm | Phase 2 rocker arms (bending loads) |
| Fiberglass tape (25mm woven) | Wrapped around pivot joints with epoxy | Moderate — wet layup | Phase 2 pivot bosses (shear loads) |
| M3 threaded rod tensile core | Through-bolt running arm length | Easy — drill and insert | Alternative to aluminium tube core |

**Not needed for Phase 1** — at 1.1 kg total weight, PLA alone is more than adequate.

**Reinforcement details (Phase 2)**:

- **Carbon fiber strips**: Bond 1mm × 10mm pultruded carbon fiber strips to the flat faces of rocker and bogie arms using structural epoxy (e.g. JB Weld or West System). Apply strips to both top and bottom faces for maximum effect. Increases bending stiffness 3-5× compared to bare PETG/ASA. Lightly sand the printed surface and the strip with 120 grit before bonding. Clamp or tape in place for 24hr cure.
- **Fiberglass tape**: Wrap 25mm woven fiberglass tape around pivot joint bosses with epoxy (wet layup). 2-3 wraps provides substantial shear reinforcement at the most stressed points. Sand smooth after cure.
- **Differential bar tensile core**: Run an M3 threaded rod through the full length of the differential bar as a tensile core. The rod carries tension loads while the printed shell handles compression, preventing the bar from snapping under suspension articulation.

### 7.3 Waterproofing (Phase 2)

The rover will encounter rain. Electronic bays need weatherproofing:

| Method | Application | Notes |
|---|---|---|
| Silicone gaskets | Panel joints | Cut from silicone sheet, compressed between panels |
| Hot glue seams | Non-removable panel joints | Quick, flexible, waterproof |
| Conformal coating | PCBs (ESP32, motor drivers) | Protects electronics from moisture |
| Drain holes | Body floor corners | Let condensation escape, prevent pooling |
| IP54 cable glands | Wire entry points | Thread through gland, tighten nut |
| Coroplast splash guards | Under body | Cheap, light, deflects road spray from wheels |

---

## 8. Estimated Print Times

### 8.1 Phase 1 Total

From EA-08 print summary:
- ~26 core parts (46 total including hardware)
- ~69 hours total print time
- ~1 kg PLA filament needed

At an average of 6-8 hours of printing per day (overnight prints), Phase 1 printing takes **~8-10 days**.

### 8.2 Phase 2 Total

| Category | Parts | Est. Time |
|---|---|---|
| Body panels (top deck) | 30 | 90 hrs |
| Body panels (sides) | 10 | 30 hrs |
| Electronics bay | 6 | 18 hrs |
| Rocker arms (2× 2 halves) | 4 | 24 hrs |
| Bogie arms (2× 2 halves) | 4 | 12 hrs |
| Wheels (6× 2 halves) | 12 | 36 hrs |
| Steering brackets | 4 | 8 hrs |
| Fixed motor mounts | 2 | 4 hrs |
| Camera mast sections | 3 | 9 hrs |
| Arm segments | 12 | 24 hrs |
| Fridge housing | 4 | 12 hrs |
| Camera mounts | 7 | 7 hrs |
| Connectors/brackets | 40 | 40 hrs |
| Diff bar adapters | 3 | 3 hrs |
| **TOTAL** | **~141** | **~317 hrs** |

At 8 hours printing per day: **~40 days of printing**.

### 8.4 Community Benchmarks

These open-source rover builds provide useful reference points:
- **Sawppy** (Roger Cheng): ~3 kg filament, 3 spools. PLA prototyped then reprinted in PETG. 3 perimeters, 0.4mm nozzle. Wheels print outer-face-down without supports.
- **ExoMy** (ESA): 1.5 kg PLA, 0.15mm layers, 20% infill. ~2 weeks print time for all structural parts. 2.5 kg total rover weight.

### 8.3 Filament Budget (Phase 2)

| Material | Weight | Spools (1kg) | Cost |
|---|---|---|---|
| PETG (body panels, brackets) | ~3.5 kg | 4 | $80-100 |
| ASA (structural: arms, mounts) | ~1.0 kg | 1 | $25-30 |
| TPU (wheel tyres) | ~0.3 kg | 1 | $25-30 |
| Failed prints/waste (~15%) | ~0.7 kg | — | included |
| **TOTAL** | **~5.5 kg** | **6 spools** | **~$130-160** |

The EA-06 budget allocated $60 for 4× PETG 1kg spools. The revised estimate is $130-160 for complete filament needs — an additional ~$70-100. This should be flagged as a budget adjustment.

---

## 9. Common Failure Modes & Prevention

| Failure Mode | Cause | Prevention |
|---|---|---|
| Warping (corners lift from bed) | Uneven cooling, poor adhesion | Glue stick or painter's tape, 60°C bed (PLA), brim on large parts |
| Layer delamination | Under-extrusion, too fast, too cold | Calibrate e-steps, slow down, raise temp 5°C |
| Bearing seat too tight | Print shrinkage | Test-print bearing block first, adjust ±0.1mm |
| Bearing seat too loose | Over-extrusion | Reduce flow by 2-5%, reprint |
| Heat-set insert crooked | Rushed installation | Use insert tip, go slow, press straight |
| Heat-set insert blowout | Insufficient wall thickness | Ensure ≥2.4mm wall around insert |
| Stringing between parts | Wet filament, poor retraction | Dry filament (4hrs at 65°C), increase retraction |
| Elephant's foot (first layer bulge) | Nozzle too close, bed too hot | Raise nozzle 0.02mm, reduce bed temp 5°C |
| Part snaps at layer line | Weak inter-layer adhesion | More walls, higher temp, slower speed |
| D-shaft bore too tight | Thermal contraction | Print 0.1mm oversized, ream to fit |

### 9.1 Filament Drying

All filaments absorb moisture from air, degrading print quality (though PLA is less sensitive than PETG/ASA):

| Material | Max moisture | Dry temp | Dry time | Storage |
|---|---|---|---|---|
| PLA | 0.10% | 45°C | 4-6 hours | Vacuum bag + desiccant (less critical than PETG) |
| PETG | 0.08% | 65°C | 4-6 hours | Vacuum bag + desiccant |
| ASA | 0.04% | 80°C | 4-6 hours | Vacuum bag + desiccant |
| TPU | 0.15% | 50°C | 4-8 hours | Vacuum bag + desiccant |

**Drying method**: Kitchen oven at minimum setting with door cracked, or a food dehydrator ($30). Print straight from the dryer if possible.

---

## 10. Recommended Print Sequence (Phase 2)

The build sequence should match the assembly order from EA-08, starting with the hardest-to-replace structural parts:

1. **Bearing test blocks** — validate all bearing seat dimensions
2. **Heat-set insert test block** — validate insert hole size
3. **2020 extrusion connectors** (40×) — needed first for frame assembly
4. **Rocker arms** (4 halves) — long prints, structural
5. **Bogie arms** (4 halves) — structural
6. **Differential bar adapters** (3×)
7. **Steering brackets** (4×) — needs servo + motor for test fit
8. **Fixed motor mounts** (2×)
9. **Wheels** (12 halves) — can print while assembling suspension
10. **TPU tyres** (6×) — last (need hub dimensions confirmed)
11. **Electronics bay floor panels** (6×) — needed for electronics layout
12. **Side panels** (10×) — can print while wiring electronics
13. **Camera mounts** (7×) — needed for sensor installation
14. **Camera mast sections** (3×)
15. **Arm segments** (12×) — can print during software development
16. **Fridge housing** (4×) — low priority
17. **Top deck panels** (30×) — last — cosmetic, can run rover without them

---

*Document EA-11 v2.0 — 2026-03-23 (major rewrite: PLA for Phase 1, CTC Bizer printer, 4-quadrant body, x3g workflow)*

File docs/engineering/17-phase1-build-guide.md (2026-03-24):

# Engineering Analysis 17: Phase 1 Build Guide

**Document**: EA-17
**Date**: 2026-03-15
**Purpose**: Step-by-step build guide for the 0.4-scale prototype rover, from ordering parts through to first drive. Designed to be followed linearly.
**Depends on**: EA-08 (Parts Spec), EA-09 (GPIO), EA-10 (Steering), EA-11 (3D Printing)

---

## Step 0: Prerequisites

### 0.1 Tools Required

| Tool | Purpose | Estimated Cost |
|---|---|---|
| 3D Printer (CTC Bizer) | Print all structural parts (225×145×150mm bed, x3g via GPX) | Already owned |
| Soldering iron + solder | Heat-set inserts, wiring | Already owned |
| Wire strippers | Motor/servo wiring | Already owned |
| Hex key set (1.5mm, 2mm, 5mm) | M2, M3, M8 fasteners | ~$5 |
| Small Phillips screwdriver | SG90 servo screws | Already owned |
| Multimeter | Voltage checks, continuity | Already owned |
| 22mm drill bit (hand twist) | Ream bearing holes if needed | ~$3 |
| Needle-nose pliers | Holding nuts, crimping | Already owned |
| Tweezers | Placing heat-set inserts | Already owned |
| Hot glue gun | Cable management, temporary fixes | Already owned |
| Computer with Arduino IDE / CLI | Programming ESP32-S3 | Already owned |

### 0.2 Software Required

| Software | Purpose | Status |
|---|---|---|
| Arduino IDE 2.x or arduino-cli | ESP32 programming | Install ESP32-S3 board support |
| Slicer (Cura) | Generate G-code for CTC Bizer | Install and configure for CTC Bizer |
| GPX 2.6.8 | Convert gcode → x3g for CTC Bizer | Installed at `C:\Users\charl\bin\gpx.exe` |
| Fusion 360 | CAD modelling | Installed with MCP-Link add-in |
| Web browser | Rover control UI | Already available |

---

## Step 1: Order Parts (~$102, delivery 1-3 weeks)

### 1.1 First Order (Start Immediately)

Order these first — filament arrives first so you can start printing while waiting for electronics.

| # | Item | Qty | Source | Est. Cost |
|---|---|-----|---|---|
| 1 | PLA filament 1kg (grey or white) | 2 | Amazon | $30 |
| 2 | M3 heat-set inserts (brass, 5.7mm OD × 4.6mm) | 50 | AliExpress/Amazon | $3 |
| 3 | M3 bolt assortment (8mm, 12mm, 16mm socket cap) | 1 set | Amazon | $6 |
| 4 | M3 nut assortment | 1 set | included | — |
| 5 | M8 × 40mm hex bolts | 8 | Hardware store | $3 |
| 6 | M8 nyloc nuts | 8 | Hardware store | $2 |
| 7 | M8 washers | 16 | Hardware store | $1 |
| 8 | 608ZZ bearings | 12 | Amazon | $5 |

**Subtotal: ~$40**

### 1.2 Second Order (Electronics)

| # | Item | Qty | Source | Est. Cost |
|---|---|-----|---|---|
| 9 | ESP32-S3 DevKitC-1 (N16R8, USB-C) | 1 | AliExpress | $8 |
| 10 | GA12-N20 DC gearmotors (6V, 100RPM, 1:100 ratio, metal gearbox) | 6 | AliExpress | $18 |
| 11 | SG90 micro servos | 4 | AliExpress | $8 |
| 12 | L298N motor driver modules | 2 | AliExpress | $6 |

**Subtotal: ~$40**

### 1.3 Third Order (Power + Misc)

| # | Item | Qty | Source | Est. Cost |
|---|---|-----|---|---|
| 13 | 2S LiPo 2200mAh (7.4V, XT60) | 1 | Amazon/HobbyKing | $12 |
| 14 | 2S LiPo balance charger | 1 | Amazon | $8 |
| 15 | Power switch (toggle or rocker) | 1 | Amazon | $2 |
| 16 | Jumper wire set (M-M, M-F) | 1 | Amazon | $3 |
| 17 | Mini breadboard | 1 | Amazon | $2 |
| 18 | 8mm steel rod (300mm length) | 1 | Hardware store | $2 |
| 19 | 100nF ceramic capacitors | 6 | Amazon/AliExpress | $1 |

**Subtotal: ~$30**

**Grand total: ~$109** (slightly over $102 budget due to larger filament spool — worth the extra margin for reprints).

---

## Step 2: 3D Printing (~65 hours over 8-10 days)

### 2.1 Printer Setup

1. Level bed (paper or 0.1mm feeler gauge — slight drag)
2. Load PLA filament (left extruder only)
3. Set PLA temperature: **200-210°C nozzle, 60°C bed**
4. Apply glue stick or painter's tape for adhesion
5. Right nozzle: remove or park (raise 1-2mm above left)
6. Run calibration test card (from `3d-print/calibration/`) to verify dimensions
7. See `docs/plans/ctc-bizer-guide.md` for full CTC Bizer setup
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

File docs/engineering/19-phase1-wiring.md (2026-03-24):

# Engineering Analysis 19: Phase 1 Complete Wiring Guide

**Document**: EA-19
**Date**: 2026-03-15
**Purpose**: Provide a complete, step-by-step wiring reference for the 0.4-scale Phase 1 prototype rover. This document contains everything needed to wire the rover from bare components to a fully connected system.
**Depends on**: EA-03 (Power System), EA-08 (Phase 1 Spec), EA-09 (GPIO Pin Map), EA-15 (Safety Systems)

---

## 1. Power Distribution Diagram

### 1.1 Main Power Path

```
                           PHASE 1 POWER DISTRIBUTION
                           ==========================

  +-----------+     +--------+     +--------+     +------------------+
  | 2S LiPo   |     | 5A     |     | Kill   |     | Power            |
  | 7.4V      +---->+ Blade  +---->+ Switch +---->+ Distribution     |
  | 2200mAh   |     | Fuse   |     | (rear) |     | (solder/terminal)|
  | XT60 plug |     +--------+     +--------+     +----+------+------+
  +-----------+                                        |      |
                                                       |      |
                         +-----------------------------+      |
                         |                                    |
                         v                                    v
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

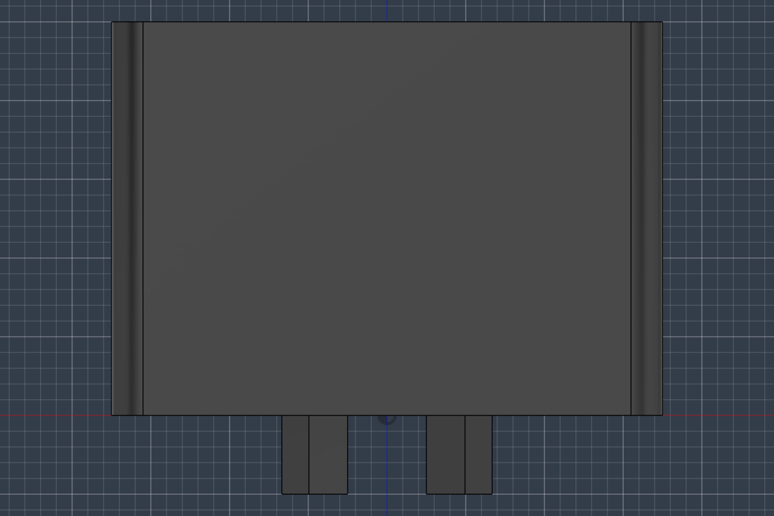
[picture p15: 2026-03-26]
3d-print/screenshots/SteeringBracket_front.png

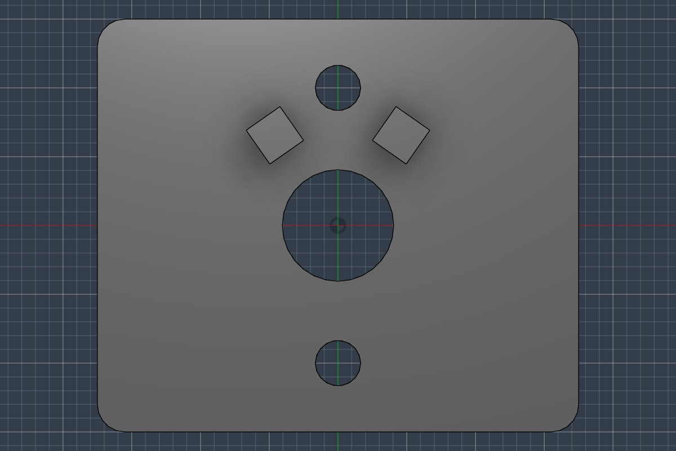
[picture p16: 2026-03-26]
3d-print/screenshots/SteeringBracket_bottom.png

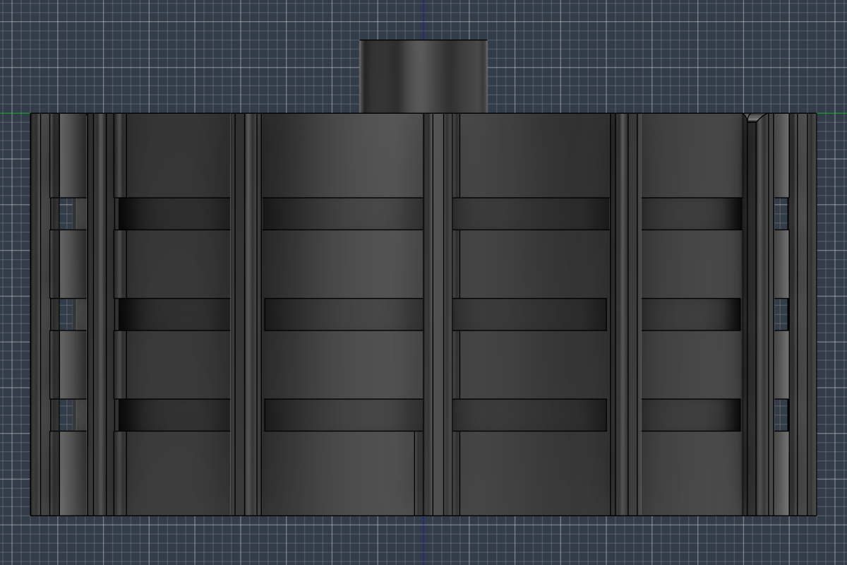
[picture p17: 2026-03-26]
3d-print/screenshots/RoverWheelV3_right.png

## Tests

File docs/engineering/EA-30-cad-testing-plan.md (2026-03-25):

# Engineering Analysis 30: CAD Testing Plan

**Document**: EA-30
**Date**: 2026-03-25
**Author**: Claude Opus 4.6 + Charlie
**Status**: Active
**Purpose**: Define a systematic, budget-conscious testing plan for validating all 29 Phase 1 STLs before committing to the full ~72-hour print campaign.
**Depends on**: EA-08 (Phase 1 Spec), EA-11 (3D Printing Strategy), EA-25 (Suspension Audit), EA-26 (Suspension Design), EA-27 (Steering System), EA-28 (Systems Integration), EA-29 (CAD Redesign)
**See also**: `docs/plans/pre-print-checklist.md`, `docs/plans/pre-print-master-plan.md`

---

## 1. Testing Philosophy

### 1.1 Core Principles

Every gram of PLA, every hour of print time, and every heat-set insert costs real money and irreplaceable time. The CTC Bizer is an older machine that has not been used in years. The CAD scripts have never produced a physical part. This testing plan exists to catch problems when they are cheap to fix (a 15-minute test print) rather than expensive to discover (an 8-hour body quadrant that doesn't mate with its neighbour).

**The three rules:**

1. **Never batch-print untested geometry.** Print one, measure it, confirm fitment, then print the remaining copies.
2. **Test interfaces, not aesthetics.** A bearing seat that is 0.1mm too tight will wreck the entire suspension. A cosmetic blemish on a body panel is irrelevant at this stage.
3. **Fix at the source.** If a bearing bore is wrong, adjust `BEARING_OD` in `rover_cad_helpers.py` so every part that uses `make_bearing_seat()` inherits the correction. Do not sand individual parts to fit.

### 1.2 The Test-Print-Validate-Adjust Cycle

```
  +-- DESIGN -------+     +-- PRINT --------+     +-- VALIDATE -----+
  |                  |     |                  |     |                  |
  | rover_cad_       | --> | Slice in Cura    | --> | Measure with     |
  | helpers.py       |     | gpx -m cr1d      |     | digital calipers |
  | (shared dims)    |     | Print on Bizer   |     | (+-0.02mm)       |
  |                  |     |                  |     |                  |
  +------------------+     +------------------+     +--------+---------+
          ^                                                  |
          |               PASS? -----> Continue              |
          |                                                  |
          +--- ADJUST <---- FAIL? ---------------------------+
               (change shared constant by 0.05mm)
```

Every test print follows this cycle. The key insight is that `rover_cad_helpers.py` is the single source of truth for all hardware interface dimensions. A tolerance fix to one constant propagates automatically to every script that uses it.

### 1.3 Budget Context

| Item | Cost | Notes |
|---|---|---|
| PLA filament | ~GBP 18/kg spool | Phase 1 needs ~1 kg total |
| Calibration prints (all 4 phases below) | ~50g PLA, ~GBP 1 | Less than 5% of total filament |
| Full print campaign | ~1000g PLA, ~GBP 18 | ~72 hours, 76 parts |
| Heat-set inserts | ~GBP 3 for 50 | M3, 5.7mm OD, brass knurled |
| Failed full-size part | 30-200g PLA + 1-10 hours | This is what we are trying to avoid |

Spending 2-3 hours and 50g of filament on calibration prints can save 20+ hours and 300g+ of wasted material from a single bad tolerance propagating through the entire build.

### 1.4 Tools Required

- Digital calipers (resolution 0.02mm or better) -- essential, non-negotiable
- 608ZZ bearing (at least 1 from the 12 ordered)
- 8mm steel rod offcut (~50mm is sufficient for socket testing)
- M3 heat-set insert (at least 2 for test installation)
- Soldering iron with conical or insert tip
- N20 motor (1 from the 6 ordered)
- SG90 servo (1 from the 4 ordered)
- M3x12mm bolt + nut (at least 2)
- Marker pen (for marking tight/loose areas)

---

## 2. Phase 1: Calibration Prints (MUST DO FIRST)

These three prints establish the baseline accuracy of the CTC Bizer and validate the two most critical press-fit interfaces (608ZZ bearing and 8mm tube socket). **Do not print any rover parts until all three calibration prints pass.**

### 2.1 Print #1: `calibration_test_card.stl`

**Location**: `3d-print/calibration/calibration_test_card.stl`
**Estimated print time**: ~30 minutes
**Estimated filament**: ~8g PLA
**Purpose**: General printer dimensional accuracy across multiple feature sizes.

| Slicer Setting | Value |
|---|---|
| Layer height | 0.2mm |
| Walls | 4 |
| Infill | 50% gyroid |
| Nozzle temp | 205 C |
| Bed temp | 60 C |
| Speed | 40 mm/s |
| Supports | Off |
| Brim | None |

**Measurements to take** (record all in a table with target, actual, and deviation):

| Feature | Target (mm) | Actual (mm) | Deviation (mm) | Pass/Fail |
|---|---|---|---|---|
| Overall X dimension | (as designed) | | | +/-0.3mm |
| Overall Y dimension | (as designed) | | | +/-0.3mm |
| Overall Z dimension | (as designed) | | | +/-0.3mm |
| Hole diameter (small) | 3.0mm | | | +/-0.15mm |
| Hole diameter (medium) | 8.0mm | | | +/-0.15mm |
| Hole diameter (large) | 22.0mm | | | +/-0.15mm |
| Boss/post diameter | (as designed) | | | +/-0.2mm |
| Wall thickness | 4.0mm | | | +/-0.2mm |

**Pass criteria**: All features within stated tolerances.

**If FAIL**:
- If holes are consistently undersized: this is normal for FDM. Calculate the average hole shrinkage factor. Expect 0.1-0.3mm undersized.
- If outer dimensions are oversized: check e-steps calibration (over-extrusion). Reduce flow rate by 2-5% in Cura.
- If Z-height is wrong: check first layer height (Z-offset too close = elephant's foot, too far = poor adhesion).
- Record all correction factors in `cad/scripts/printer_calibration.py`.

### 2.2 Print #2: `bearing_test_piece.stl`

**Location**: `3d-print/calibration/bearing_test_piece.stl`
**Estimated print time**: ~15-20 minutes
**Estimated filament**: ~6g PLA
**Purpose**: Validate 608ZZ bearing press-fit at 22.15mm bore, 7.2mm depth.

This is the single most critical test print. Nine bearings must fit into seats across 4 different part types (steering_bracket, bogie_pivot_connector, body_quadrant, and the bearing test piece itself). The shared `BEARING_OD` constant (22.15mm, which is 22.0mm nominal + 0.15mm oversize for PLA) governs all of them.

| Slicer Setting | Value |
|---|---|
| Layer height | 0.2mm |
| Walls | 4-5 |
| Infill | 60% gyroid |
| Nozzle temp | 205 C |
| Bed temp | 60 C |
| Speed | 35-40 mm/s |
| Supports | Off |
| Brim | None |

**Test procedure**:

1. Remove print from bed, allow to cool to room temperature (PLA contracts as it cools).
2. Measure the bearing bore diameter with calipers at 3 points (0, 60, 120 degrees). Record all three.
3. Measure the bore depth. Target: 7.2mm.
4. Attempt to seat a 608ZZ bearing (22.0mm OD, 7.0mm width) by hand pressure only.
5. Rate the fit:

| Rating | Description | Action |
|---|---|---|
| **A -- Perfect** | Bearing pushes in with firm hand pressure, stays in place when inverted, no rattle | PASS -- proceed to Phase 2 |
| **B -- Slightly tight** | Bearing enters with strong thumb pressure or light tap with plastic handle | Acceptable for now, note it. May loosen after a few insertions. |
| **C -- Too tight** | Bearing will not enter without hammering or the print cracks | FAIL -- increase `BEARING_OD` by 0.05mm in `rover_cad_helpers.py`, re-export, reprint |
| **D -- Too loose** | Bearing drops in freely and rattles or falls out when inverted | FAIL -- decrease `BEARING_OD` by 0.05mm in `rover_cad_helpers.py`, re-export, reprint |
| **E -- Way off** | Bearing doesn't remotely fit (>0.5mm discrepancy) | Printer calibration issue. Return to Print #1 and diagnose. |

**Also measure**:
- Shaft bore (8.1mm target): slide 8mm rod through the centre hole. Should pass through freely with minimal play.
- Entry chamfer: visually confirm 0.3mm chamfer is present at bore mouth.

**Maximum iterations**: 3. If the bearing still does not fit after 3 reprints with 0.05mm adjustments each time, investigate whether the printer has a systematic dimensional error (e.g., X/Y steps per mm are miscalibrated).

### 2.3 Print #3: `tube_socket_test.stl`

**Location**: `3d-print/calibration/tube_socket_test.stl`
**Estimated print time**: ~15 minutes
**Estimated filament**: ~5g PLA
**Purpose**: Validate 8mm steel rod socket bore (8.2mm) and M3 grub screw retention.

The tube-and-connector suspension design (EA-25/EA-26) requires every connector to accept 8mm steel rods in slide-fit sockets, retained by M3 grub screws. The `TUBE_BORE` constant (8.2mm = 8.0mm nominal + 0.2mm clearance) governs all 6 suspension connector scripts.

| Slicer Setting | Value |
|---|---|
| Layer height | 0.2mm |
| Walls | 4-5 |
| Infill | 60% gyroid |
| Nozzle temp | 205 C |
| Bed temp | 60 C |
| Speed | 35-40 mm/s |
| Supports | Off |
| Brim | None |

**Test procedure**:

1. Measure the tube socket bore with calipers. Target: 8.2mm.
2. Insert an 8mm steel rod into the socket.
3. Rate the fit:

| Rating | Description | Action |
|---|---|---|
| **A -- Perfect** | Rod slides in smoothly with slight friction, stays when released, can be pulled out by hand | PASS |
| **B -- Tight but usable** | Rod enters with light twisting/rocking, doesn't rattle | Acceptable -- note. May improve with use. |
| **C -- Too tight** | Rod will not enter or requires excessive force | FAIL -- increase `TUBE_BORE` by 0.05mm |
| **D -- Too loose** | Rod falls out under gravity, significant play | FAIL -- decrease `TUBE_BORE` by 0.05mm |

4. Test socket depth: rod should seat to 15mm depth (mark rod at 15mm with tape, insert until tape touches socket face).
5. Test M3 grub screw hole: thread an M3 set screw into the radial hole. It should engage and be able to press against the rod to lock it in place.
6. Test wall integrity: with the rod inserted and grub screw tightened, apply moderate lateral force to the rod. The socket wall (4mm minimum, controlled by `TUBE_WALL`) should not crack or deform visibly.

**Maximum iterations**: 3 (same approach as bearing test).

### 2.4 Calibration Phase Summary

| Print | Time | Filament | Pass Criteria |
|---|---|---|---|
| Calibration test card | 30 min | 8g | All features within tolerance |
| Bearing test piece | 20 min | 6g | 608ZZ Rating A or B |
| Tube socket test | 15 min | 5g | 8mm rod Rating A or B |
| **Possible reprints** (up to 3 iterations each) | +90 min max | +33g max | |
| **Total worst case** | ~2.5 hours | ~52g | |

**Go/No-Go gate**: All three prints must achieve at least Rating B before proceeding to Phase 2. Record the validated (golden) dimensions:

- Golden bearing bore: _____ mm (target 22.15mm)
- Golden tube socket bore: _____ mm (target 8.2mm)
- Golden shaft bore: _____ mm (target 8.1mm)

---

## 3. Phase 2: Critical Interface Validation

With the CTC Bizer calibrated and basic fits confirmed, Phase 2 tests the actual rover parts that must mate together. Print ONE of each mating pair and verify the interface before committing to full quantities.

### 3.1 Test Set A: Front Steering Corner

Print these two parts together (they fit on the bed simultaneously):

| Part | STL | Print Time | Filament |
|---|-----|---|---|
| front_wheel_connector (x1) | `suspension/front_wheel_connector.stl` | ~45 min | ~12g |
| steering_bracket (x1) | `steering/steering_bracket.stl` | ~45 min | ~15g |

**Interface checks**:

| Check | What to Verify | Target | Tool |
|---|---|---|---|
| Bolt hole alignment | 2x M3 mounting holes at 16mm spacing | Holes align when parts are mated; M3 bolt passes through both | M3x12 bolt + light |
| Heat-set insert pocket | 2x 4.8mm x 5.5mm pockets in front_wheel_connector | Insert installs flush at 170-180 C, M3 bolt threads in cleanly | Soldering iron + insert + M3 bolt |
| M3 through-hole | 2x 3.3mm clearance holes in steering_bracket | M3 bolt slides through freely | M3 bolt |
| Bearing seat (steering bracket) | 22.15mm bore, 7.2mm depth in steering_bracket | 608ZZ fits (should match calibration result) | 608ZZ bearing |
| Tube socket (front_wheel_connector) | 8.2mm bore, 15mm depth, M3 grub | 8mm rod slides in (should match calibration result) | 8mm rod |
| Assembled clearance | Parts bolt together without fouling | No interference between bodies when bolted at 16mm spacing | Visual + finger check |

**Pass criteria**: All 6 checks pass. The two parts bolt together cleanly with an M3 bolt passing through the bracket's clearance hole into the connector's heat-set insert.

### 3.2 Test Set B: Middle Wheel Station

| Part | STL | Print Time | Filament |
|---|-----|---|---|
| middle_wheel_connector (x1) | `suspension/middle_wheel_connector.stl` | ~45 min | ~14g |
| fixed_wheel_mount (x1) | `steering/fixed_wheel_mount.stl` | ~30 min | ~8g |

**Interface checks**:

| Check | What to Verify | Target |
|---|---|---|
| Bolt hole alignment | 2x M3 at 16mm spacing | Holes align, bolt passes through |
| Heat-set insert pocket | In middle_wheel_connector | Insert installs cleanly |
| M3 through-hole | In fixed_wheel_mount | Bolt slides through freely |
| N20 motor clip | 12.2 x 10.2 x 25mm pocket in fixed_wheel_mount | N20 motor snaps in, does not fall out, shaft protrudes through exit hole |
| Tube socket | In middle_wheel_connector | 8mm rod fits (should match calibration) |

**Pass criteria**: All checks pass. Motor clips securely. Bolt alignment correct.

### 3.3 Test Set C: Differential Pivot

| Part | STL | Print Time | Filament |
|---|-----|---|---|
| differential_pivot_housing (x1) | `suspension/differential_pivot_housing.stl` | ~60 min | ~20g |

**Interface checks**:

| Check | What to Verify | Target |
|---|---|---|
| Bearing seat | 22.15mm bore for 608ZZ (centre pivot) | 608ZZ fits per calibration |
| Diff bar bore | 8.2mm through-bore for 8mm differential bar rod | Rod slides through freely, grub screw locks it |
| Flange bolt holes | M3 mounting holes for body attachment | M3 bolts pass through |
| Structural integrity | Part does not crack under moderate hand force | No visible cracking at bearing boss or flange junctions |

### 3.4 Test Set D: Steering Linkage

Print these three small parts together:

| Part | STL | Print Time | Filament |
|---|-----|---|---|
| steering_knuckle (x1) | `steering/steering_knuckle.stl` | ~30 min | ~8g |
| servo_mount (x1) | `steering/servo_mount.stl` | ~30 min | ~10g |
| steering_horn_link (x1) | `steering/steering_horn_link.stl` | ~10 min | ~2g |

**Interface checks**:

| Check | What to Verify | Target |
|---|---|---|
| SG90 pocket (servo_mount) | 22.4 x 12.2 x 12mm pocket + 32.4mm tab slots | SG90 drops in from top, tabs rest on ledges, no rattle |
| N20 clip (steering_knuckle) | 12.2 x 10.2 x 25mm motor pocket | N20 motor snaps in securely |
| Steering arm extension (knuckle) | Arm with M2 pin hole for horn link | M2 pin/screw passes through |
| Horn link pin holes | 20mm centre-to-centre, 2x M2 holes | M2 screws fit both holes, 20mm spacing verified with calipers |
| Hard stop tab (knuckle) | Tab-in-channel for +/-35 deg limit | Visual check that tab clears channel at neutral and contacts at ~35 deg rotation |

### 3.5 Test Set E: Heat-Set Insert Validation Block

This is not a rover part -- it is a simple test block to validate the heat-set insert installation process before committing to installing ~40 inserts across the actual rover parts.

**Option A**: Use the front_wheel_connector from Test Set A (it already has insert pockets).
**Option B**: Print a dedicated 30x30x15mm test block with 3 insert pockets at the CAD-specified 4.8mm bore and 5.5mm depth.

**Test procedure**:

1. Heat soldering iron to 170 C (PLA -- lower than PETG's 200-220 C).
2. Place brass insert (M3, 5.7mm OD, knurled) on top of pocket.
3. Press iron tip into the insert thread and push straight down. The surrounding PLA should melt and flow around the knurls.
4. Insert should seat flush with surface (or 0.2mm below) within 2-3 seconds.
5. Allow 10 seconds to cool.
6. Thread an M3x12 bolt into the insert. It should thread smoothly with no binding.
7. Unthread and re-thread 3 times to confirm.

**Pass/Fail criteria**:

| Result | Description | Action |
|---|---|---|
| PASS | Insert flush, straight, bolt threads smoothly 3 times | Proceed with confidence |
| Insert crooked | Insert entered at an angle | Technique issue -- practice. Use insert tip if available. Does not require CAD changes. |
| Surrounding PLA cracked | Material fractured around insert | Temperature too high -- reduce to 160 C. Or wall thickness insufficient -- increase `INSERT_BORE` wall requirement. |
| Insert sinks too deep | Insert pushed below flush | Do not push past flush. Reduce iron temperature or press duration. |
| Insert won't seat | Pocket too tight for insert OD | Increase `INSERT_BORE` by 0.1mm (currently 4.8mm / 2.4mm radius). |
| Bolt won't thread | PLA flowed into insert thread | Temperature too high -- reduce 10 C. Or clean insert thread with M3 tap after installation. |

### 3.6 Phase 2 Summary

| Test Set | Parts | Print Time | Filament | Key Interface |
|---|---|---|---|---|
| A: Front steering corner | 2 | ~90 min | ~27g | Bolt alignment, bearing, tube socket |
| B: Middle wheel station | 2 | ~75 min | ~22g | Bolt alignment, N20 clip |
| C: Differential pivot | 1 | ~60 min | ~20g | Bearing, diff bar bore |
| D: Steering linkage | 3 | ~70 min | ~20g | SG90 pocket, horn link geometry |
| E: Heat-set inserts | (reuse A) | 0 | 0 | Insert installation process |
| **Total** | **8 parts** | **~5 hours** | **~89g** | |

**Go/No-Go gate**: All interface checks pass. Any failures must be traced back to a shared constant in `rover_cad_helpers.py`, adjusted, re-exported via BatchExportAll, and the specific test piece reprinted before proceeding.

---

## 4. Phase 3: Structural Load Testing

Phase 1 is a 1.25 kg prototype operating indoors on flat surfaces. PLA at 60 MPa tensile strength provides enormous safety margins. Nevertheless, certain parts bear concentrated loads and should be tested by hand to confirm they will not fail during normal operation.

### 4.1 Load-Bearing Hierarchy

Parts ranked by structural criticality (highest to lowest):

| Rank | Part | Primary Load | Failure Mode | Consequence |
|---|---|---|---|---|
| 1 | rocker_hub_connector | Suspension articulation torque at body pivot | Tube socket cracks, bearing boss shears | Entire suspension side detaches |
| 2 | bogie_pivot_connector | Vertical load from 2 wheels, pivot torque | Bearing boss cracks, tube sockets split | Bogie detaches from rocker |
| 3 | differential_pivot_housing | Diff bar bending moment, body attachment | Flange bolts pull out, bearing boss cracks | Differential mechanism fails |
| 4 | front_wheel_connector | Vertical load from 1 wheel, steering torque | Tube socket cracks at grub screw hole | Wheel assembly detaches |
| 5 | steering_bracket | Steering torque + vertical load through bearing | Bearing bore deforms, mounting holes strip | Wheel cannot steer |
| 6 | body_quadrant (x4) | All loads from suspension pivots | Bearing boss cracks where it meets panel wall | Entire side sags |
| 7 | fixed_wheel_mount | Motor torque reaction, vertical load | N20 clip cracks, bolts pull from inserts | Middle wheel loses drive |

### 4.2 Hand-Test Procedures

These tests require no equipment beyond the printed parts, hardware, and your hands. They should be performed on the single test prints from Phase 2 before committing to full quantities.

**Test 4.2.1: Tube Socket Twist Test**

- Parts: rocker_hub_connector or front_wheel_connector with 8mm rod inserted and grub screw tightened.
- Procedure: Grip the connector body in one hand and the protruding rod in the other. Apply a firm twisting force (try to rotate the rod relative to the connector). Then apply a firm bending force (try to lever the rod sideways).
- Pass: Rod does not rotate in socket. No visible cracking at the socket walls or grub screw hole. No audible cracking sounds.
- Fail: Rod slips in socket (grub screw not engaging), or wall cracks appear (wall too thin or infill too low).

**Test 4.2.2: Bearing Boss Compression Test**

- Parts: Any part with a bearing seat (steering_bracket, bogie_pivot_connector) with 608ZZ bearing installed.
- Procedure: Place the part on a flat surface. Press firmly on the bearing with your thumb (approximately 5-10 kg force). Rock the bearing side to side.
- Pass: No deformation, no cracking, bearing does not move relative to the part.
- Fail: Bearing boss cracks, or bearing shifts in the seat.

**Test 4.2.3: N20 Motor Clip Retention Test**

- Parts: steering_knuckle or fixed_wheel_mount with N20 motor inserted.
- Procedure: Hold the part and try to pull the motor out by gripping the motor body. Shake the part vigorously.
- Pass: Motor stays clipped in. Motor does not rattle. Shaft still turns freely.
- Fail: Motor slides out with light force, or motor rattles significantly.

**Test 4.2.4: Bolt Pull-Out Test (Heat-Set Insert)**

- Parts: Any part with installed heat-set insert (from Phase 2 Test Set E).
- Procedure: Thread an M3x12 bolt through a mating bracket into the insert. Tighten with a screwdriver (not a ratchet or power tool -- just firm hand tightening). Then try to pull the bolt out axially.
- Pass: Insert remains seated. No cracking. Bolt holds firmly.
- Fail: Insert pulls out of PLA, or surrounding material cracks.

**Test 4.2.5: Body Quadrant Seam Flex Test**

- Parts: 2 adjacent body quadrants (e.g., FL + FR) bolted together at the seam.
- Procedure: Hold one quadrant flat and try to flex the other up/down at the seam. Apply moderate force.
- Pass: Seam feels rigid. No visible gap opening. No bolt loosening.
- Fail: Seam flexes more than ~2mm, or gap opens between panels.

### 4.3 PLA Infill and Perimeter Recommendations by Structural Tier

Based on the load hierarchy above:

| Tier | Parts | Walls | Infill | Layer Height | Rationale |
|---|---|---|---|---|---|
| **Critical** (Rank 1-3) | rocker_hub_connector, bogie_pivot_connector, differential_pivot_housing | 5 | 60% gyroid | 0.16mm | Maximum wall thickness around tube sockets and bearing bores. 0.16mm layers for better resolution on critical bore features. |
| **Structural** (Rank 4-5) | front_wheel_connector, middle_wheel_connector, steering_bracket, fixed_wheel_mount | 4-5 | 50-60% gyroid | 0.2mm | High infill around motor clips and bearing seats. Standard layer height adequate. |
| **Body** (Rank 6) | body_quadrant (x4) | 4 | 20% gyroid | 0.2mm | Large panels do not need high infill. Strength comes from walls and ribs. Add 5-8mm brim for bed adhesion. |
| **Light duty** | servo_mount, steering_horn_link, cable_clip, strain_relief_clip, top_deck tiles | 3 | 30% gyroid | 0.2mm | Low loads. Filament savings. |
| **Minimal** | fuse_holder_bracket, switch_mount_plate, battery_tray | 3 | 20-30% gyroid | 0.2mm | Near-zero structural load. |

---

## 5. Phase 4: Sub-Assembly Integration

After individual parts pass Phase 2 interface checks and Phase 3 load tests, build three sub-assemblies to verify that parts work together as a system.

### 5.1 Sub-Assembly A: Rocker-Bogie Arm (1 side)

**Parts needed** (all previously printed and tested):

| Part | Qty | Source |
|---|-----|---|
| rocker_hub_connector | 1 | Phase 2 or new print |
| bogie_pivot_connector | 1 | New print |
| front_wheel_connector | 2 | Phase 2 + 1 new |
| middle_wheel_connector | 1 | Phase 2 |
| 608ZZ bearing | 3 | (rocker pivot, bogie pivot, front steering) |
| 8mm steel rod segments | 3 | Cut to length per EA-25 |
| M3 grub screws | 3 | To lock rods in sockets |

**Assembly procedure**:

1. Press bearings into rocker_hub_connector (body pivot) and bogie_pivot_connector.
2. Cut three 8mm rod segments: rocker front tube, rocker rear tube, bogie tube (lengths from `generate_rover_params.py`).
3. Insert rod ends into tube sockets. Tighten M3 grub screws.
4. Verify that the bogie pivots freely around its bearing relative to the rocker.
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

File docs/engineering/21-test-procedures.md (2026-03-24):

# Engineering Analysis 21: Test Procedures & Acceptance Criteria

**Document**: EA-21
**Date**: 2026-03-15
**Purpose**: Define structured test procedures, pass/fail criteria, and acceptance thresholds for every subsystem of the Mars rover across all build phases. Follows a V-model approach from unit tests through system-level acceptance.
**Depends on**: EA-08 (Phase 1 Spec), EA-09 (GPIO), EA-10 (Steering), EA-12 (UART Protocol), EA-15 (Safety Systems), EA-17 (Build Guide), EA-19 (Wiring)

---

## 1. Test Philosophy

### 1.1 V-Model Testing Approach

The rover follows a V-model development lifecycle where each design stage has a corresponding test stage:

```
Requirements  ─────────────────────────────────────  Acceptance Tests
    │                                                       ▲
    ▼                                                       │
System Design  ────────────────────────────────  System Tests
    │                                                  ▲
    ▼                                                  │
Module Design  ──────────────────────  Integration Tests
    │                                        ▲
    ▼                                        │
Implementation  ──────────  Unit Tests
```

| V-Model Stage | EA Documents | Test Level |
|---|---|---|
| Requirements | EA-01 to EA-06 | Acceptance tests (Section 5) |
| System design | EA-08, EA-10, EA-13 | System tests (Section 4) |
| Module design | EA-09, EA-12, EA-15, EA-19 | Integration tests (Section 3) |
| Implementation | Firmware, ROS2 nodes | Unit tests (Section 2) |

### 1.2 Pass/Fail Criteria Methodology

Every test has:
- **Test ID**: Unique identifier (UT-xxx for unit, IT-xxx for integration, ST-xxx for system, AT-xxx for acceptance)
- **Description**: What is being tested
- **Setup**: Hardware/software prerequisites
- **Procedure**: Numbered steps to execute
- **Expected result**: Observable outcome if the system is working correctly
- **Pass criteria**: Quantitative threshold that must be met
- **Fail action**: What to do if the test fails

A test **passes** only if ALL pass criteria are met. A partial pass is recorded as a fail with notes.

### 1.3 Test Equipment Required

| Equipment | Purpose | Estimated Cost |
|---|---|---|
| Multimeter (with continuity beep) | Voltage, current, resistance, continuity checks | Already owned |
| Tape measure (5m) | Driving accuracy, turn radius measurement | Already owned |
| Stopwatch / phone timer | Timing e-stop response, battery runtime | Already owned |
| Spirit level | Body levelness over obstacles | Already owned |
| Protractor or angle finder | Steering angle verification | ~$5 |
| USB-UART adapter (CP2102 or FTDI) | UART loopback and protocol testing | ~$5 |
| Serial terminal software (minicom/PuTTY) | UART debugging and monitoring | Free |
| Oscilloscope (optional) | PWM verification, signal integrity | Nice-to-have |
| Wooden blocks (20mm, 40mm) | Suspension obstacle tests | Scrap wood |
| 5m straight line (tape on floor) | Straight-line accuracy test | Masking tape |
| Bench power supply (optional) | Isolated motor testing | Nice-to-have |
| Phone with browser | WebSocket control, PWA testing | Already owned |
| Computer with Arduino CLI | Firmware upload, serial monitor | Already owned |

---

## 2. Unit Tests

### 2.1 ESP32-S3 Firmware Tests

#### Motor Control Module

| Test ID | Description | Setup | Procedure | Expected Result | Pass Criteria |
|---|---|---|---|---|---|
| UT-M01 | Individual motor forward | Single motor connected to L298N OUT1/OUT2, ESP32 powered, wheels off ground | 1. Upload motor test sketch. 2. Command motor W1 forward at 50% PWM. 3. Observe wheel rotation. | Wheel spins in the designated forward direction at moderate speed. | Wheel rotates forward continuously for 5 seconds without stall or reversal. |
| UT-M02 | Individual motor reverse | Same as UT-M01 | 1. Command motor W1 reverse at 50% PWM. 2. Observe wheel rotation. | Wheel spins in reverse direction. | Wheel rotates reverse continuously for 5 seconds. Direction is opposite to UT-M01. |
| UT-M03 | Motor speed ramp | Same as UT-M01, serial monitor open | 1. Command motor from 0% to 100% over 200ms. 2. Monitor PWM output on serial. | Motor accelerates gradually, no instant jump. | PWM increments by no more than RAMP_RATE (10) per 20ms tick. Serial output confirms ramp profile. |
| UT-M04 | Motor brake (coast) | Same as UT-M01 | 1. Spin motor at 50%. 2. Command IN1=LOW, IN2=LOW. 3. Try to spin wheel by hand. | Wheel decelerates and spins freely. | Wheel can be turned by hand with minimal resistance after 2 seconds. |
| UT-M05 | Motor brake (active) | Same as UT-M01 | 1. Spin motor at 50%. 2. Command IN1=HIGH, IN2=HIGH. 3. Try to spin wheel by hand. | Wheel stops and resists turning. | Wheel cannot be easily turned by hand (motor terminals shorted). |
| UT-M06 | PWM resolution | Same as UT-M01, multimeter on motor leads | 1. Set PWM to 25%, measure average voltage. 2. Set to 50%, measure. 3. Set to 75%, measure. 4. Set to 100%, measure. | Voltage scales proportionally with PWM duty cycle. | Measured voltage within 15% of theoretical (duty% x supply voltage, accounting for L298N drop). |
| UT-M07 | Parallel motor pair | W2+W3 wired in parallel to L298N OUT3/OUT4 | 1. Command left mid+rear forward at 50%. 2. Observe both wheels. | Both W2 and W3 spin in the same direction at similar speed. | Both wheels spin forward, neither stalls. |
| UT-M08 | Motor free-spin current | Ammeter in series with one motor output | 1. Command motor at 100% PWM, no load. 2. Read current. | Low current draw (motor spinning freely). | Current draw < 0.2A per motor at no load. |
| UT-M09 | Motor stall current | Ammeter in series with motor, wheel locked | 1. Lock wheel so it cannot turn. 2. Command motor at 100% PWM. 3. Read stall current immediately. 4. Cut power within 3 seconds to prevent overheating. | High current draw (motor stalled). | Stall current measured and recorded. Expected 0.8-1.5A for GA12-N20. Verify L298N can handle this (2A rated). |

#### Steering Module

| Test ID | Description | Setup | Procedure | Expected Result | Pass Criteria |
|---|---|---|---|---|---|
| UT-S01 | Servo centre position | Single SG90 connected to ESP32, horn attached loosely | 1. Send 1500us pulse to servo. 2. Measure horn angle with protractor. | Servo moves to mechanical centre position. | Horn within 5 degrees of straight-ahead position. |
| UT-S02 | Servo sweep range | Same as UT-S01 | 1. Sweep from 500us to 2400us in 100us steps. 2. Observe range of motion. 3. Listen for grinding at extremes. | Servo sweeps approximately 180 degrees without mechanical binding. | Full range of motion achieved. No grinding or stalling at endpoints. |
| UT-S03 | Ackermann angle calculation | Serial monitor open, no hardware needed | 1. Command a turn with radius = 500mm (Phase 1 scale). 2. Read calculated FL, FR, RL, RR angles from serial. | Inner wheel angle is larger than outer wheel angle. Rear wheels are opposite sign to front. | Angles match EA-10 Section 5 worked examples within 1.0 degree. |
| UT-S04 | Servo trim adjustment | Servo mounted on steering bracket | 1. Set centre (1500us). 2. Observe if wheel is straight. 3. Apply trim offset. 4. Re-centre. | Trim offset corrects any mechanical misalignment. | After trim, wheel straight-ahead when centred. Deviation < 2 degrees. |
| UT-S05 | Servo trim calibration SOP | All 4 servos mounted on steering brackets, wheels attached, protractor | 1. Power on, command all servos to centre (1500μs). 2. For each servo: measure angle between wheel and chassis using protractor. 3. If deviation > 2°, calculate trim: trim_μs = deviation_deg × 10.31 μs/deg. 4. Apply trim to config.h SERVO_TRIM_FL/FR/RL/RR. 5. Re-upload firmware. 6. Re-measure. 7. Repeat until all 4 within 2°. | All wheels point straight ahead when centred. | All 4 servos within 2° of straight-ahead after trim. Record final trim values in test log. |
| UT-S06 | Steering mode switch | All 4 servos connected | 1. Switch from Ackermann to Point Turn mode. 2. Switch to Crab Walk mode. 3. Switch back to Ackermann. | Servos reconfigure to correct angles for each mode. | All 4 wheels reach correct positions within 500ms of mode change. No servo jitter on switch. |

#### Sensor Module

| Test ID | Description | Setup | Procedure | Expected Result | Pass Criteria |
|---|---|---|---|---|---|
| UT-SN01 | Battery ADC reading | Voltage divider on GPIO14, multimeter on battery | 1. Read ADC value. 2. Calculate battery voltage using scale factor (3.128). 3. Compare to multimeter reading. | ADC-derived voltage matches multimeter. | Within 5% of multimeter reading across the range 6.4V to 8.4V. |
| UT-SN02 | Battery voltage stages | Bench supply set to test voltages, or wait for discharge | 1. Set voltage to 7.0V (normal). Verify normal operation. 2. Set to 6.8V (warning). Verify warning. 3. Set to 6.4V (critical). Verify motor cutoff. | Three-stage battery protection activates at correct thresholds. | Warning triggers at 3.4-3.5V/cell (6.8-7.0V pack). Critical triggers at 3.2-3.4V/cell (6.4-6.8V pack). |
| UT-SN03 | Encoder pulse counting | Encoder W1 connected to GPIO38/39, serial monitor | 1. Slowly rotate wheel one full revolution by hand. 2. Read tick count from serial. | Tick count matches encoder specification (pulses per revolution). | Tick count within 5% of rated PPR per revolution. Count increments on forward rotation, decrements on reverse. |
| UT-SN04 | Encoder quadrature | Same as UT-SN03 | 1. Rotate wheel forward, record count direction. 2. Rotate wheel backward, record count direction. | Forward and reverse produce opposite count directions. | Forward: positive increment. Reverse: negative increment. No missed counts over 10 revolutions. |

#### E-Stop Module

| Test ID | Description | Setup | Procedure | Expected Result | Pass Criteria |
|---|---|---|---|---|---|
| UT-E01 | E-stop button detection | Tactile button on GPIO46, serial monitor | 1. Press E-stop button. 2. Read GPIO46 state on serial. 3. Release button. | GPIO reads HIGH when pressed (connected to 3.3V via internal pull-down). | GPIO46 transitions from LOW to HIGH on press, returns to LOW on release. No bounce (debounce in firmware). |
| UT-E02 | E-stop motor cutoff | Motors running at 50%, E-stop button ready | 1. Start all motors at 50% PWM. 2. Press E-stop button. 3. Observe motors. 4. Measure time from press to stop. | All motors immediately stop. | All motor PWM set to 0 within 20ms of button press. No motor movement after stop. |
| UT-E03 | E-stop persistence | Motors stopped by E-stop | 1. While in E-stop state, command motors via WebSocket. 2. Observe motors. | Motor commands are rejected while E-stop is active. | No motor movement occurs. WebSocket reports E-stop state. |
| UT-E04 | E-stop recovery | Rover in E-stop state | 1. Press E-stop button again to release. 2. Send resume command from phone app. 3. Command motors forward. | Rover returns to normal operation after explicit recovery. | Motors respond to commands only after BOTH button release AND resume command received. |

#### Electronics Module

| Test ID | Description | Setup | Procedure | Expected Result | Pass Criteria |
|---|---|---|---|---|---|
| UT-E01 | L298N 3.3V logic verification | L298N connected to ESP32-S3, motor connected to output, oscilloscope on EN/IN pins | 1. Set IN1=HIGH, IN2=LOW. Measure IN1 voltage (expect 3.3V). 2. Verify motor runs in one direction. 3. Swap IN1/IN2. Verify motor reverses. 4. Set ENA PWM 50%. Verify motor speed reduces. 5. Repeat at EN=10% PWM — verify motor still responds. | Motor responds to all commands at 3.3V logic levels. No commands ignored. | Motor responds to all commands. No commands ignored. L298N logic threshold confirmed <3.3V. |

**Note**: UT-E01 (Electronics) tests L298N logic levels. The E-Stop module below also uses UT-E01–E04 for E-stop button tests — these are in separate subsections.

#### Latency Module

| Test ID | Description | Setup | Procedure | Expected Result | Pass Criteria |
|---|---|---|---|---|---|
| UT-L01 | Command latency measurement | Phone with PWA, rover powered on WiFi, high-speed camera or oscilloscope on motor output | 1. Record phone screen and motor simultaneously. 2. Press forward button. 3. Review recording frame-by-frame. 4. Measure time from button touch event to motor voltage appearing. 5. Repeat 10 times, record average and max. | Motor voltage appears shortly after button press. | Average latency <200ms. Max latency <500ms. |

#### Motor Control Module (continued)

| Test ID | Description | Setup | Procedure | Expected Result | Pass Criteria |
|---|---|---|---|---|---|
| UT-M10 | Acceleration ramp test | Single motor connected, encoder (or visual tachometer), ESP32 logging | 1. Command full speed from standstill. 2. Log PWM value vs time (firmware ramp). 3. Verify ramp time matches config.h RAMP_MS. 4. Verify no current spike exceeds fuse rating. | Motor accelerates smoothly from 0 to max within target ramp time. | 0→max in ≤2s. Current spike <5A. |

#### UART Module (Phase 2 preparation, testable with loopback)

| Test ID | Description | Setup | Procedure | Expected Result | Pass Criteria |
|---|---|---|---|---|---|
| UT-U01 | UART TX output | ESP32 TX (GPIO43) connected to USB-UART adapter RX, serial terminal on PC | 1. ESP32 sends `$PNG*19\n` every second. 2. Monitor on PC serial terminal. | Ping messages appear on PC terminal. | All messages received with correct format and checksum. 0% loss over 60 seconds. |
| UT-U02 | UART RX parsing | USB-UART adapter TX connected to ESP32 RX (GPIO44), serial terminal | 1. Type `$MOT,50,50,50,-50,-50,-50*7A\n` from PC terminal. 2. Observe ESP32 serial output for ACK. | ESP32 parses command and responds with ACK. | ESP32 prints parsed motor values matching input. Sends `$ACK,MOT*2A\n` back. |
| UT-U03 | Checksum validation | Same as UT-U02 | 1. Send message with correct checksum. 2. Send message with incorrect checksum (change one hex digit). | Correct message is processed. Incorrect message is rejected. | Valid message: ACK received. Invalid message: ERR code 1 (checksum mismatch) received. No motor action on bad checksum. |
| UT-U04 | UART timeout safety | USB-UART adapter connected, motors running | 1. Send MOT commands at 50Hz for 5 seconds. 2. Stop sending commands. 3. Wait 200ms. 4. Observe motors. | Motors stop after 200ms of no commands. | Motors reach 0% PWM within 250ms of last received command. ERR code 8 (command_timeout) sent. |

### 2.2 ROS2 Node Tests (pytest) — Phase 2

All ROS2 node tests use the pytest framework with `launch_testing` for integration, and direct function calls for unit testing.
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

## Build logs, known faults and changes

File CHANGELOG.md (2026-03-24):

# Changelog

All notable changes to this project will be documented in this file.
Format follows [Keep a Changelog](https://keepachangelog.com/en/1.1.0/).
This project uses [Semantic Versioning](https://semver.org/spec/v2.0.0.html).

## [0.3.0] - 2026-03-24

### Added
- EA-22 Requirements Specification (formal FR/PR/DIM/ELEC/LEARN/DFT/MOD)
- EA-23 Wire Harness (58-wire schedule, connectors, cable routing, colour codes)
- EA-24 Robotic Arm Study (Phase 2 feasibility, 3-DOF concept, Phase 1 mount prep)
- Maintenance guide with after-session, weekly, monthly, and crash checklists
- Disassembly guide with per-component procedures
- Prototype data capture template (build log, dimensional verification, performance)
- Future design improvements document (Phase 2 lessons learned template)
- Firmware: arm-before-drive safety (ARM/DISARM commands via WebSocket and UART)
- Firmware: battery-based speed limiting (50% at warning, 0% at critical)
- Firmware: stall detection (2s timeout, PWM > 20% threshold)
- Firmware: steering rate limiting (60 deg/s max, smooth interpolation)
- Firmware: 5 LED patterns (idle, armed, driving, warning, error/SOS)
- Firmware: leds.h module with arm/disarm interface
- PWA: ARM/DISARM toggle buttons on Drive tab
- PWA: telemetry cards for arm state, speed limit, stall detection
- PWA: gamepad and D-pad gated on armed state
- ROS2: /rover/arm topic subscriber in UART bridge node
- UART: $ARM and $DSA NMEA commands
- CAD: camera mast mount (RL top deck tile, 4x M3 heat-set)
- CAD: antenna dish detail (RR top deck tile, cosmetic)
- CAD: arm mount bosses (FL body quadrant, 4x M3 for Phase 2 arm)
- CAD: RTG-style radiator fin detail (RL/RR rear wall, cosmetic)
- CAD: MLI blanket edge ridges (all quadrants, cosmetic)
- CAD: rover tire script (TPU 95A, 86mm OD, 48 treads)
- Wiring diagrams: 4 Mermaid source files + rendered SVGs
- CI: firmware unit test job (42 pytest tests)
- CI: docs check now covers EA-00 through EA-24
- MIT LICENSE file
- CHANGELOG.md (this file)

### Changed
- Body quadrant walls: 3mm -> 4mm, added panel line grooves and corner chamfers
- Bogie arm walls: 2.5mm -> 3mm
- Bogie arm length: 120mm -> 180mm (corrected 0.4x scaling of 450mm)
- Diff bar rod: 200mm -> 300mm (250mm pivot span + 25mm overhang each side)
- Rocker arm bogie pivot boss: 26mm -> 30mm OD (wall thickness fix)
- Cable exit holes: 10x5mm -> 12x8mm (JST-XH connector compatible)
- Electronics tray: added 4 corner gussets (5x5x2mm)
- Wheel: added spoke holes, rim lips, USE_TPU_TIRE toggle
- Top deck: added panel line grid (30mm spacing, 0.5mm deep)
- Bearing oversize: 0.1mm -> 0.15mm in generate_rover_params.py
- Battery color thresholds in PWA: 50/20% -> 30/5% (matches firmware)
- Service worker cache bumped to rover-v5
- Printer references: Ender 3 -> CTC Bizer throughout
- Material references: PETG -> PLA for Phase 1 throughout
- Bearing count: 10 -> 11 throughout
- Parts count: 22 -> 26, print time: 65hr -> 69hr
- URDF: bogie length 0.120 -> 0.180, diff bar 0.200 -> 0.300
- .gitignore: added .x3g, .gcode, .pytest_cache, coverage files

### Fixed
- motorCurrent[] undefined in esp32.ino -> changed to motorSpeed[]
- RAD_TO_DEG undefined in steering.h -> added #ifndef guard to config.h
- OTA port hardcoded 3232 in ota.h -> uses OTA_PORT from config.h
- URDF typo: <xac:property -> <xacro:property
- EA-00 master handbook: stale Ender 3 and PETG references
- EA-02 summary table: min turn radius ~300mm -> 397mm
- EA-08 summary table: bogie 120 -> 180, body quadrant text
- EA-11: major rewrite for CTC Bizer, PLA, 4 quadrants, x3g workflow
- EA-15: watchdog API updated for ESP32 Arduino Core v3.x
- EA-19: added motor caps, 5V BEC documentation
- EA-20: bogie, bearing count, Y_SPLIT corrections
- Pre-print checklist: diff bar rod flag resolved (200 -> 300mm)
- Assembly reference: servo centre 1472us -> 1500us

## [0.2.0] - 2026-03-23

### Added
- Complete ESP32-S3 firmware (7 modules: config, motors, steering, sensors, webserver, UART, OTA)
- Firmware compiles: 1042KB flash (79%), 53KB RAM (16%)
- PWA phone app (Catppuccin Mocha/Latte, D-pad, camera, telemetry, settings, OTA)
- 7 ROS2 packages scaffolded (10 nodes)
- 42 firmware host-based pytest tests
- 134 ROS2 pytest tests with mock framework
- GitHub Actions CI/CD (compile, build, lint, docs check)
- Gazebo garden world + 21 simulation scenarios
- 22 engineering analysis documents (EA-00 through EA-21)
- 18 Fusion 360 CAD scripts for all Phase 1 parts
- Print strategy, pre-print checklist, assembly reference
- CTC Bizer guide, shopping list, complete BOM

### Changed
- Initial project structure established

## [0.1.0] - 2026-03-14

### Added
- Initial project design document (v1.3)
- Project directory structure
- Basic README with architecture overview

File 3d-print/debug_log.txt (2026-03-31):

OK: BearingTestPiece — 0 bodies

OK: ServoMount — 0 bodies

OK: SteeringKnuckle — 0 bodies

OK: RockerHubConnector — 0 bodies

OK: FrontWheelConnector — 0 bodies

OK: MiddleWheelConnector — 0 bodies

OK: DifferentialPivotHousing — 2 bodies

OK: SwitchMountPlate — 0 bodies

OK: BatteryTray — 0 bodies

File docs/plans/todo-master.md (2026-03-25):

# Mars Rover Garden Robot — Master Todo List

**Created**: 2026-03-15
**Last Updated**: 2026-03-25
**Status**: 98% design-complete. All software, firmware, docs, CAD scripts, and CAD redesign done. 29/29 STLs exported. 0% physically built. Next: printer setup, parts ordering, print campaign.

---

## Legend

- [ ] Not started
- [~] In progress
- [x] Complete

---

## 1. DOCUMENTATION & CONSISTENCY (Can do now — no hardware needed)

### 1.1 Design Doc Updates
- [x] Update design doc v1.2 → v1.3 with all research-backed corrections
  - [x] Update EA reference from "EA-01 through EA-12" to "EA-01 through EA-18"
  - [x] Update Nav2 controller section (DWB → RegulatedPurePursuit)
  - [x] Update EKF section (single → dual EKF architecture)
  - [x] Update motion model (REEDS_SHEPP → DUBIN)
  - [x] Remove spin recovery behavior references
  - [x] Add USB camera tiered bandwidth approach
  - [x] Add carbon fiber reinforcement mention for Phase 2
  - [x] Cross-reference EA-18 binary protocol for Phase 2

### 1.2 Cross-Reference Audit (DONE — 3 HIGH issues fixed, 3 MEDIUM noted, 5 LOW noted)
- [x] Verify all 31 EAs (EA-00 through EA-30) reference each other correctly where dependent
- [x] Check EA-02 torque calcs match EA-05 weight budget values — consistent (34.2kg design weight)
- [x] Check EA-03 power budget matches EA-02 motor selections — consistent (peak 24A = 6×4A stall)
- [x] Check EA-06 cost breakdown matches all component selections — **fixed**: filament $10→$20
- [x] Verify EA-08 Phase 1 spec dimensions match EA-01 suspension geometry — consistent (0.4× scaling)
- [x] Verify EA-09 GPIO pinmap covers all sensors in EA-04 — **gap confirmed**: 6× ultrasonic, 3× DS18B20, audio, LCD need I2C expander (PCA9535/PCF8574). BME280/BH1750/VEML6075 fit on existing I2C bus
- [x] Verify EA-10 Ackermann values match EA-08 wheelbase dimensions — consistent (900mm/360mm)
- [x] Verify EA-17 build guide references correct EA numbers — correct
- [x] **Fixed**: EA-02 Ackermann wheelbase 680mm→900mm (was using projected ground distance)
- [x] **Fixed**: EA-05 motor name JGB37-520→Chihai CHR-GM37-520 (185g, matching EA-02)
- [x] **Fixed**: EA-05 motor driver BTS7960→Cytron MDD10A (matching EA-02)

### 1.3 Missing Documentation
- [x] Create project README.md at repository root (project overview, phase status, quick links)
- [x] Create `docs/datasheets/README.md` listing required datasheets with download links
- [x] Create wiring diagram document for Phase 1 (EA-19: ESP32-S3 → motors/sensors/servos)
- [x] Create CAD preparation guide (EA-20, reference dimensions from EA-08 for Fusion 360)
- [x] Create test procedures & acceptance criteria (EA-21)
- [x] Create Master Engineering Handbook (EA-00, compiles all EAs)
- [x] Create design methodology document (V-model, phases, review gates)
- [x] Create Fusion 360 MCP setup guide
- [x] Create parametric CAD generation script (cad/scripts/generate_rover_params.py)
- [x] Document the backup strategy (`docs/plans/backup-strategy.md` + `scripts/backup.bat`)

---

## 2. SOFTWARE — Config & Launch Fixes (Can do now)

### 2.1 Nav2 & Localization (DONE this session)
- [x] Fix nav2_params.yaml: DWBLocalPlanner → RegulatedPurePursuitController
- [x] Fix nav2_params.yaml: REEDS_SHEPP → DUBIN motion model
- [x] Fix nav2_params.yaml: Remove spin recovery behavior
- [x] Fix nav2_params.yaml: Add `use_rotate_to_heading: false`
- [x] Fix ekf.yaml: Single EKF → Dual EKF (local + global)
- [x] Fix ekf.yaml: Add navsat_transform configuration
- [x] Fix nav.launch.py: Single ekf_node → dual ekf_local + ekf_global + navsat_transform
- [x] Fix hardware.launch.py: Inline placeholder URDF → real xacro file reference

### 2.2 URDF / Simulation
- [x] Uncomment Gazebo plugins in rover.urdf.xacro (diff_drive, joint_state, LiDAR, IMU, depth camera)
- [x] Create standalone `simulation.launch.py` for Gazebo testing
- [x] Add Gazebo world file for garden environment (grass + gravel path + slopes + obstacles + furniture)
- [ ] Test URDF loads correctly: `check_urdf rover.urdf` (requires Jetson)
- [ ] Verify TF tree matches EA-13 specification (requires Jetson)

### 2.3 ROS2 Node Implementation (All scaffolded — needs on-hardware testing)
- [x] `uart_bridge_node.cpp` — NMEA parsing implemented (ENC, IMU, USS, BAT, STS + odometry)
  - [x] Parse $RENC (encoder data) + compute differential drive odometry
  - [x] Parse $RIMU (IMU quaternion, gyro, accel with covariance)
  - [x] Parse $RBAT (battery voltage + SoC)
  - [x] Parse $REST / $RSTS (E-stop and status)
  - [x] Parse $RUSS (6x ultrasonic → Range messages)
  - [x] Send $CMTR (motor commands)
  - [x] Send $CSTR (steering commands)
  - [x] Handle watchdog timeout
  - [x] Publish to ROS2 topics (/wheel_odom, /imu/data, /battery_state, /ultrasonic/*)
- [x] `ackermann_controller.py` — Ackermann geometry implemented (EA-10)
- [x] `geofence_node.py` — GPS boundary check with haversine
- [x] `waypoint_follower.py` — GPS waypoint navigation via Nav2 action server
- [x] `camera_manager.py` — tiered USB camera management (3 tiers)
- [x] `yolo_node.py` — TensorRT YOLO inference node
- [x] `depth_processor.py` — OAK-D stereo depth + PointCloud2
- [x] `mission_planner.py` — BT.CPP behaviour tree integration
- [x] `joy_mapper.py` — gamepad teleop with dead zone + speed modes
- [x] `web_server_node.py` — WebSocket server for PWA telemetry
- [ ] **All nodes need on-hardware validation** (requires Jetson + sensors)

### 2.4 ESP32-S3 Firmware (Phase 1 — All scaffolded, needs on-hardware testing)
- [x] Implement full NMEA protocol parser (EA-12) — checksum, command routing, telemetry
- [x] Implement motor control (L298N, 4 channels) — PWM, direction, acceleration ramping
- [x] Implement Ackermann steering (EA-10) — 4 servos, point turn, crab walk
- [x] Implement encoder reading (6 channels) — interrupt-driven, speed/distance/odometry
- [x] Implement IMU reading (BNO055 via I2C) — quaternion, gyro, accel, calibration
- [x] Implement battery monitoring — ADC voltage divider, SoC lookup, low battery warning
- [x] Implement E-stop system (EA-15) — hardware pin, software command, UART watchdog
- [x] Implement ultrasonic sensors (6 channels) — non-blocking trigger/echo, median filter
- [x] Add WiFi AP mode for initial configuration
- [x] Add OTA firmware update support
- [x] Test compile for ESP32-S3 DevKitC-1 (1045KB/79% flash, 53KB/16% RAM — v0.3.0, ESP32 Core v3.3.7)
- [ ] **All modules need on-hardware validation** (requires ESP32-S3 + peripherals)

---

## 3. CAD & MECHANICAL (Fusion 360 + CTC Bizer)

### 3.1 Fusion 360 CAD Scripts — COMPLETE (CAD redesign v1.0.0-cad-redesign)
- [x] Install Fusion 360 Personal + MCP-Link add-in
- [x] Create parametric dimension script (`generate_rover_params.py`)
- [x] Design body quadrants — `body_bottom_*.py` (FL/FR/RL/RR), `top_deck_tile.py`
- [x] Design wheels — `rover_wheel_v3.py` (Mars-aesthetic spokes, O-ring grooves, 608ZZ seat)
- [x] Design suspension — tube+connector approach (EA-25/26):
  - [x] `rocker_hub_connector.py`, `bogie_pivot_connector.py`
  - [x] `front_wheel_connector.py`, `middle_wheel_connector.py`
  - [x] `differential_pivot_housing.py`, `cable_clip.py`
- [x] Design steering — offset parallel drive + horn link 4-bar (EA-27):
  - [x] `steering_bracket.py`, `steering_knuckle.py`, `steering_horn_link.py`
  - [x] `servo_mount.py`, `fixed_wheel_mount.py`
- [x] Design drivetrain — `motor_mount_n20.py`
- [x] Design electronics — `electronics_tray.py`, `strain_relief.py`, `fuse_holder.py`, `switch_mount.py`
- [x] Design calibration — `bearing_test.py`, `tube_socket_test.py`
- [x] Create 6 reference models (N20, SG90, 608ZZ, ESP32, L298N, 2S LiPo)
- [x] Create BatchExportAll script (29 STL exports)
- [x] Create printer calibration script (`printer_calibration.py`, zeroed — needs real data)
- [x] Full CAD redesign: all scripts rewritten with fillets, chamfers, shared helpers (cad_helpers.py)
- [x] Run BatchExportAll — 29/29 STLs exported successfully (arc direction bug fixed)
- [x] EA-29 engineering documentation written (CAD redesign record)
- [x] rover_assembly_v2.py created for full assembly visualization
- [x] Git tagged v1.0.0-cad-redesign

### 3.2 Printer Setup & Calibration (CTC Bizer, not used in years)
- [ ] Mechanical inspection (belts, rods, nozzle, bed)
- [ ] Park right extruder, bed level, load PLA
- [ ] Print XYZ calibration cube — measure ±0.2mm
- [ ] Print bearing test piece — test 608ZZ press-fit
- [ ] Print tube socket test — test 8mm rod slide-fit
- [ ] Iterate up to 3× until snug push-fit achieved
- [ ] Update `printer_calibration.py` with real measured values

### 3.3 Print Campaign (~72 hrs, 29 unique parts × copies ≈ 76 pieces)
- [ ] Batch A: 1× Wheel + 1× Steering bracket (gate: motor D-shaft, bearing seat)
- [ ] Batch B: 1× Servo mount + horn link + knuckle (gate: SG90 pocket, link geometry)
- [ ] Batch C: 5× remaining wheels (gate: O-ring grooves, batch quality)
- [ ] Batch D: 3× Steering brackets + 2× fixed mounts (gate: all 6 wheel mounts)
- [ ] Batch E: 3× Servo mounts + horn links + knuckles (gate: 4 steering assemblies)
- [ ] Batch F: 11× Suspension connectors (gate: tube socket fit, bearing fit)
- [ ] Batch G: Diff pivot housing (gate: centre bearing, diff bar clamp)
- [ ] Batch H: 12× Cable clips (gate: wire bundle fit)
- [ ] Batch I: Electronics tray (gate: ESP32 + L298N standoffs)
- [ ] Batch J: Body FL + FR (gate: tongue/groove, bearing boss)
- [ ] Batch K: Body RL + RR (gate: rocker pivots, bed clearance)
- [ ] Batch L: 4× Top deck tiles (gate: snap clips, seam alignment)
- [ ] Batch M: Strain relief + fuse holder + switch mount (gate: fit)
- [ ] Post-processing: sand, clean, verify all fits
- [ ] Install heat-set inserts (~40, soldering iron at 170-180°C for PLA)

---

## 4. ELECTRONICS & WIRING (After CAD/print, before firmware testing)

### 4.1 Phase 1 Component Procurement
- [x] Create Phase 1 shopping list with specific UK supplier links (see `docs/plans/phase1-shopping-list.md`)
  **Note**: Some items below are Phase 2 components, not Phase 1. Per EA-08, Phase 1 uses N20 motors (not Chihai), SG90 servos (not MG996R), 2S LiPo (not 3S), and L298N drivers. Chihai motors, MG996R servos, 3S LiPo, and buck converters are Phase 2 items. See `docs/plans/phase1-shopping-list.md` for the correct Phase 1 list.
  - [ ] ESP32-S3 DevKitC-1 N16R8
  - [ ] L298N motor drivers (x2, for 4 motor channels + 2 spare)
  - [ ] N20 6V 100RPM gear motors (x6)
  - [ ] SG90 micro servos (x4)
  - [ ] Hall effect encoders (x6, or motors with built-in encoders)
  - [ ] BNO055 IMU breakout
  - [ ] HC-SR04 ultrasonic sensors (x6)
  - [ ] 2S LiPo battery (7.4V, for Phase 1)
  - [ ] LM2596 buck converters (Phase 2 only — not needed for Phase 1)
  - [ ] 608ZZ bearings (x12, 9 needed + 3 spares)
  - [ ] M3 heat-set inserts (CNC Kitchen style, 100-pack)
  - [ ] M3 screws assorted (M3x8, M3x12, M3x16, M3x20)
  - [ ] JST connectors (for modular wiring)
  - [ ] Wire (22AWG signal, 18AWG power)
  - [ ] E-stop mushroom button (normally closed)
  - [ ] Kill switch for battery
  - [ ] PLA filament (2-3 spools, 1kg each)
  - [ ] TPU filament (1 spool for tyres) (Phase 2 — CTC Bizer cannot print TPU)

### 4.2 Electronics Assembly
- [x] Create wiring harness design (EA-23: 57-wire schedule, connectors, colour codes, build order)
- [x] Create wiring diagrams (EA-19: 4 ASCII diagrams + 4 rendered Mermaid SVGs)
- [ ] Solder/connect ESP32-S3 development breadboard
- [ ] Wire motor drivers (L298N, power + signal)
- [ ] Wire steering servos (signal + 5V power bus)
- [ ] Wire encoder sensors (interrupt pins)
- [ ] Wire IMU (I2C SDA/SCL + power)
- [ ] Wire ultrasonic sensors (trigger/echo pins)
- [ ] Wire battery monitoring (voltage divider)
- [ ] Wire E-stop circuit (breaks motor power, signals ESP32)
- [ ] Wire power distribution (battery → BMS → buck converters → rails)
- [ ] Cable management and labelling
- [ ] Bench test all electronics before installing in chassis

---

## 5. PHASE 1 BUILD & TEST (Physical assembly + initial testing)

### 5.1 Mechanical Assembly
- [ ] Assemble rocker-bogie suspension to chassis
- [ ] Install 608ZZ bearings at all pivot points
- [ ] Attach differential bar
- [ ] Install steering knuckles and servos
- [ ] Mount motors to motor mounts
- [ ] Attach wheels and TPU tyres
- [ ] Install electronics tray in chassis
- [ ] Route all cables through channels
- [ ] Verify wheel clearance and steering range of motion
- [ ] Check centre of gravity (should be low and centred)

### 5.2 Firmware Bring-Up (on bench, before full assembly)
- [ ] Flash ESP32-S3 with Phase 1 firmware
- [ ] Verify UART communication (NMEA messages over serial monitor)
- [ ] Test individual motor control (forward/reverse each motor)
- [ ] Test steering servos (full range, centre calibration)
- [ ] Test encoder reading (spin wheels by hand, verify counts)
- [ ] Test IMU orientation (tilt in each axis, verify data)
- [ ] Test ultrasonic sensors (hand in front of each, verify distance)
- [ ] Test battery voltage reading
- [ ] Test E-stop (hardware and software)
- [ ] Test watchdog timeout (disconnect UART, verify motors stop)

### 5.3 Integration Testing
- [ ] Drive straight line test (encoder-based distance verification)
- [ ] Ackermann turn test (verify inner/outer wheel angle differential)
- [ ] Point turn test (front/rear opposite)
- [ ] Crab walk test (all wheels same angle)
- [ ] Obstacle detection test (ultrasonics → emergency stop)
- [ ] Slope test (30° incline, verify torque is sufficient)
- [ ] Battery runtime test (continuous driving, log voltage over time)
- [ ] Terrain test: grass, gravel, pavement, mixed
- [ ] Suspension articulation test (one wheel on obstacle, verify body stays level)

---

## 6. PHASE 2 — JETSON + FULL AUTONOMY (After Phase 1 validated)

### 6.1 Jetson Orin Nano Super Setup
- [ ] Flash JetPack 6.x
- [ ] Install ROS2 Humble (or Jazzy)
- [ ] Build rover workspace (`colcon build` all 7 packages)
- [ ] Configure UART connection to ESP32 (/dev/ttyTHS1)
- [ ] Test `ros2 launch rover_bringup hardware.launch.py`

### 6.2 Sensor Integration
- [ ] Mount and configure RPLidar A1 (USB, test with `ros2 launch rplidar_ros rplidar.launch.py`)
- [ ] Mount and configure OAK-D Lite (DepthAI + ROS2 driver)
- [ ] Mount and configure USB cameras (udev rules for persistent names)
- [ ] Mount and configure GPS module (u-blox M8N/M9N, NMEA → ROS2)
- [ ] Calibrate cameras (checkerboard calibration → update camera_params.yaml)
- [ ] Verify TF tree (`ros2 run tf2_tools view_frames`)

### 6.3 Navigation Stack
- [ ] Test SLAM (slam_toolbox online_async, drive around garden, save map)
- [ ] Test localization (load saved map, verify position)
- [ ] Test Nav2 path planning (send goal via rviz2 or foxglove)
- [ ] Test obstacle avoidance (place obstacle, verify replanning)
- [ ] Tune RegulatedPurePursuit parameters (lookahead, velocities)
- [ ] Tune costmap parameters (inflation radius, obstacle clearing)
- [ ] Test geofence boundary (drive toward edge, verify warning/stop)
- [ ] Test waypoint following (GPS waypoints in garden)

### 6.4 Perception
- [ ] Export YOLOv8n to TensorRT FP16 engine
- [ ] Test object detection (people, animals, obstacles)
- [ ] Integrate detections into costmap
- [ ] Test depth estimation from OAK-D stereo
- [ ] Verify detection → obstacle avoidance pipeline end-to-end

### 6.5 Autonomy
- [x] Create BT.CPP v4 behaviour tree XML missions (patrol, explore, return_home, safety_subtree)
- [ ] Test patrol mission (predefined waypoints, loop)
- [ ] Test explore mission (frontier exploration)
- [ ] Test return-to-home on low battery
- [ ] Test behaviour tree safety pre-emption
- [ ] Test PWA remote control via WebSocket

### 6.6 Binary UART Upgrade (EA-18)
- [x] Implement COBS framing on ESP32-S3 (uart_binary.h, gated by PHASE2_BINARY_PROTOCOL)
- [x] Implement CRC-16/CCITT on both ends
- [x] Switch baud rate to 460800
- [x] Implement packed struct message encoding
- [ ] Verify with loopback test
- [ ] Switch `#define PHASE2_BINARY_PROTOCOL` compile flag
- [ ] Benchmark: measure actual latency and bandwidth utilisation

### 6.7 Phase 2 Mechanical Upgrades
- [ ] Reprint chassis at 1.0 scale in PETG/ASA
- [ ] Apply carbon fiber strip reinforcement to rocker/bogie arms
- [ ] Apply UV protection (sand → primer → paint → clear coat)
- [ ] Install weatherproofing (IP44/IP54 seals per EA-14)
- [ ] Install solar panels + MPPT controller
- [ ] Install 6S LiPo pack with BMS
- [ ] Build and install robotic arms
- [ ] Build and install camera mast (pan/tilt)
- [ ] Install mini fridge compartment

---

## 7. PHASE 3 — METAL CHASSIS (Long-term)

- [ ] Design metal chassis (aluminium extrusion or sheet metal)
- [ ] Machine/order metal rocker and bogie arms
- [ ] Upgrade bearings (sealed for outdoor use)
- [ ] Upgrade motors (larger, sealed, with metal gearboxes)
- [ ] Add suspension springs/dampers
- [ ] Full weatherproofing to IP55+
- [ ] Glass coffee table surface
- [ ] Professional wiring harness

---

## 8. PWA APP ENHANCEMENTS (Can do anytime)

- [x] Implement real-time telemetry dashboard (battery, speed, heading, GPS, IMU, uptime)
- [x] Implement live camera streaming (MJPEG from Jetson web_server_node, source selector, snapshot)
- [x] Implement interactive map (Leaflet.js, rover position, geofence circle, waypoints, trail)
- [x] Implement gamepad input support (Gamepad API, controller mapping, speed modes)
- [x] Implement D-pad touch control for manual driving (in PWA and ESP32 embedded web UI)
- [x] Implement mission planner UI (patrol/explore/return home, status indicator)
- [x] Implement settings page (speed limit, sensitivity, steering mode, geofence, servo trim)
- [x] Implement firmware update trigger (OTA from PWA via Jetson, progress bar, restart button)
- [x] Implement diagnostic log viewer (color-coded, 200 entries, auto-scroll)
- [x] Add PWA install prompt and offline indicator
- [x] Dark/light theme toggle (Catppuccin Mocha ↔ Latte, saved to localStorage)

---

## 9. TESTING & QUALITY (Ongoing)

- [x] Write ROS2 unit tests for each Python node (pytest: Ackermann, geofence, waypoints, camera, mission)
- [x] Write ESP32 firmware unit tests (42 pytest tests: NMEA, Ackermann, battery, COBS, CRC-16)
- [x] Create simulation test suite (21 Gazebo scenarios: mobility, sensors, nav, terrain, safety)
- [x] Create integration test: UART bridge round-trip (30 tests: NMEA codec, commands, odometry, streams)
- [ ] Create integration test: full Nav2 stack in simulation
- [x] Set up CI/CD for ROS2 packages (GitHub Actions: ESP32 compile, firmware tests, ROS2 build, lint, docs check EA-00..EA-29)
- [ ] Performance benchmarks: YOLO FPS, EKF update rate, UART throughput

---

## 10. PROJECT MANAGEMENT

- [x] Complete all 31 engineering analyses (EA-00 through EA-30)
- [x] Create Phase 1 firmware skeleton (all modules implemented)
- [x] Create ROS2 package scaffolding (all 10 nodes implemented)
- [x] Create PWA app
- [x] Research: 3D printing materials, ROS2 architecture, binary protocols
- [x] Create project README.md
- [x] Create Phase 1 shopping list (`docs/plans/phase1-shopping-list.md`)
- [x] Fix nav2_params.yaml (RegulatedPurePursuit, DUBIN, no spin)
- [x] Fix ekf.yaml (dual EKF + navsat_transform)
- [x] Fix launch files (hardware, nav, simulation)
- [x] Enable Gazebo plugins in URDF
- [x] Complete uart_bridge_node.cpp (IMU, USS, odometry)
- [x] Back up project to C: and E: drives (periodic)
- [x] Consolidate reference docs' best findings into EAs (EA-04: TensorRT export, EA-09: I2C expander strategy, EA-11: insert sizing + UV protection, EA-13: dual EKF + udev + use_sim_time)
- [x] Update CLAUDE.md when significant changes happen
- [x] Create 39 Fusion 360 CAD scripts (27 active + 4 deprecated + 6 reference + 2 superseded)
- [x] Full project audit: fix 65+ stale refs across 19 files
- [x] Create EA-28 systems integration (42 cross-domain interfaces, 6 diagrams)
- [x] Create open-source CAD reference (30+ models, 8 categories)
- [x] Render 10 Mermaid diagrams to SVG (4 wiring + 6 integration)
- [x] Complete CAD redesign: all scripts rewritten with fillets/chamfers/shared helpers, 29/29 STLs exported
- [x] Create EA-29 CAD redesign engineering documentation
- [x] Create rover_assembly_v2.py full assembly visualization script
- [x] Tag v1.0.0-cad-redesign milestone
- [~] Maintain this todo list as work progresses

---

## Priority Order (Recommended)

1. ~~**Software & docs**: Documentation, firmware, ROS2, PWA, simulation~~ **DONE**
2. ~~**CAD scripts**: 39 Fusion 360 scripts, parametric dimensions, reference models~~ **DONE**
3. ~~**Engineering audit**: 30 EAs consistent, 65+ stale refs fixed, EA-28 integration~~ **DONE**
4. ~~**CAD redesign**: All scripts rewritten with fillets/chamfers/helpers, 29/29 STLs exported, EA-29 written~~ **DONE** (v1.0.0-cad-redesign)
5. **NOW → Printer setup**: CTC Bizer calibration, bearing/tube socket test prints
6. **NOW → Order parts**: 4 orders (~£153), filament first for calibration
7. **After calibration + filament**: Print campaign (~72 hrs, 13 batches with test-fit gates)
8. **After electronics arrive**: Bench test (flash ESP32, L298N 3.3V test, servo/motor check)
9. **After all printed + tested**: Mechanical assembly (8 stages, 6-8 hrs)
10. **FIRST DRIVE**: 10 acceptance tests (EA-21), all 3 steering modes
11. **Post-drive**: Tuning, lessons learned, firmware iteration
12. **Phase 2**: Jetson, sensors, Nav2, YOLO, full autonomy, 1.0× scale
13. **Phase 3**: Metal chassis (long-term)

---

*Total items: ~200+ tasks across 10 categories*
*Software/documentation/CAD: ~98% complete (CAD redesign done, 29/29 STLs exported)*
*Hardware/physical build: 0% — next milestone is printer calibration + parts ordering*
*See `docs/plans/pre-print-checklist.md` (v3.0) for operational print workflow*

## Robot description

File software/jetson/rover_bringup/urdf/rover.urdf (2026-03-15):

<?xml version="1.0"?>
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
<robot name="mars_rover">

  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
  <link name="base_link">
    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
    <inertial>
      <mass value="0.001" />
      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
    </inertial>
  </link>

  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
  <link name="base_footprint">
    <inertial>
      <mass value="0.001" />
      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
    </inertial>
  </link>
  <joint name="base_footprint_joint" type="fixed">
    <parent link="base_link" />
    <child link="base_footprint" />
    <origin xyz="0 0 0" rpy="0 0 0" />
  </joint>

  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
  <link name="chassis">
    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
    <inertial>
      <mass value="0.45" />
      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
    </inertial>
  </link>
  <joint name="chassis_joint" type="fixed">
    <parent link="base_link" />
    <child link="chassis" />
    <origin xyz="0 0 0.100" rpy="0 0 0" />
  </joint>

  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
  <link name="left_rocker_link">
    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
    <inertial>
      <mass value="0.03" />
      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
    </inertial>
  </link>
  <joint name="left_rocker_joint" type="revolute">
    <parent link="chassis" />
    <child link="left_rocker_link" />
    <origin xyz="-0.125 -0.180 -0.040" rpy="0 0 0" />
    <axis xyz="1 0 0" />
    <limit lower="-0.2618" upper="0.2618" effort="5.0" velocity="0.5" />
    <dynamics damping="0.1" friction="0.05" />
  </joint>

  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
  <link name="wheel_fl_steer_link">
    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
    <inertial>
      <mass value="0.005" />
      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
    </inertial>
  </link>
  <joint name="wheel_fl_steer_joint" type="revolute">
    <parent link="left_rocker_link" />
    <child link="wheel_fl_steer_link" />
    <origin xyz="-0.015 0.180 -0.020" rpy="0 0 0" />
    <axis xyz="0 0 1" />
    <limit lower="-0.6109" upper="0.6109" effort="2.0" velocity="1.5" />
    <dynamics damping="0.01" friction="0.005" />
  </joint>

  <link name="wheel_fl_link">
    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
    <inertial>
      <mass value="0.04" />
      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
    </inertial>
  </link>
  <joint name="wheel_fl_link_spin_joint" type="continuous">
    <parent link="wheel_fl_steer_link" />
    <child link="wheel_fl_link" />
    <origin xyz="0 0 0" rpy="1.5708 0 0" />
    <axis xyz="0 0 1" />
    <dynamics damping="0.01" friction="0.005" />
  </joint>

  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
  <link name="left_bogie_link">
    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
    <inertial>
      <mass value="0.02" />
      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
    </inertial>
  </link>
  <joint name="left_bogie_joint" type="revolute">
    <parent link="left_rocker_link" />
    <child link="left_bogie_link" />
    <origin xyz="-0.015 0 -0.010" rpy="0 0 0" />
    <axis xyz="1 0 0" />
    <limit lower="-0.3491" upper="0.3491" effort="5.0" velocity="0.5" />
    <dynamics damping="0.1" friction="0.05" />
  </joint>

  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
  <link name="wheel_ml_link">
    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
    <inertial>
      <mass value="0.04" />
      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
    </inertial>
  </link>
  <joint name="wheel_ml_spin_joint" type="continuous">
    <parent link="left_bogie_link" />
    <child link="wheel_ml_link" />
    <origin xyz="0 0.060 -0.010" rpy="1.5708 0 0" />
    <axis xyz="0 0 1" />
    <dynamics damping="0.01" friction="0.005" />
  </joint>

  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
  <link name="wheel_rl_steer_link">
    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
    <inertial>
      <mass value="0.005" />
      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
    </inertial>
  </link>
  <joint name="wheel_rl_steer_joint" type="revolute">
    <parent link="left_bogie_link" />
    <child link="wheel_rl_steer_link" />
    <origin xyz="0 -0.060 -0.010" rpy="0 0 0" />
    <axis xyz="0 0 1" />
    <limit lower="-0.6109" upper="0.6109" effort="2.0" velocity="1.5" />
    <dynamics damping="0.01" friction="0.005" />
  </joint>

  <link name="wheel_rl_link">
    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
    <inertial>
      <mass value="0.04" />
      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
    </inertial>
  </link>
  <joint name="wheel_rl_link_spin_joint" type="continuous">
    <parent link="wheel_rl_steer_link" />
    <child link="wheel_rl_link" />
    <origin xyz="0 0 0" rpy="1.5708 0 0" />
    <axis xyz="0 0 1" />
    <dynamics damping="0.01" friction="0.005" />
  </joint>

  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
  <link name="right_rocker_link">
    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
    <inertial>
      <mass value="0.03" />
      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
    </inertial>
  </link>
  <joint name="right_rocker_joint" type="revolute">
    <parent link="chassis" />
    <child link="right_rocker_link" />
    <origin xyz="0.125 -0.180 -0.040" rpy="0 0 0" />
    <axis xyz="1 0 0" />
    <limit lower="-0.2618" upper="0.2618" effort="5.0" velocity="0.5" />
    <dynamics damping="0.1" friction="0.05" />
  </joint>

  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
  <link name="wheel_fr_steer_link">
    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
    <inertial>
      <mass value="0.005" />
      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
    </inertial>
  </link>
  <joint name="wheel_fr_steer_joint" type="revolute">
    <parent link="right_rocker_link" />
    <child link="wheel_fr_steer_link" />
    <origin xyz="0.015 0.180 -0.020" rpy="0 0 0" />
    <axis xyz="0 0 1" />
    <limit lower="-0.6109" upper="0.6109" effort="2.0" velocity="1.5" />
    <dynamics damping="0.01" friction="0.005" />
  </joint>

  <link name="wheel_fr_link">
    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
    <inertial>
      <mass value="0.04" />
      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
    </inertial>
  </link>
  <joint name="wheel_fr_link_spin_joint" type="continuous">
    <parent link="wheel_fr_steer_link" />
    <child link="wheel_fr_link" />
    <origin xyz="0 0 0" rpy="1.5708 0 0" />
    <axis xyz="0 0 1" />
    <dynamics damping="0.01" friction="0.005" />
  </joint>

  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
  <link name="right_bogie_link">
    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
    <inertial>
      <mass value="0.02" />
      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
    </inertial>
  </link>
  <joint name="right_bogie_joint" type="revolute">
    <parent link="right_rocker_link" />
    <child link="right_bogie_link" />
    <origin xyz="0.015 0 -0.010" rpy="0 0 0" />
    <axis xyz="1 0 0" />
    <limit lower="-0.3491" upper="0.3491" effort="5.0" velocity="0.5" />
    <dynamics damping="0.1" friction="0.05" />
  </joint>

  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
  <link name="wheel_mr_link">
    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
    <inertial>
      <mass value="0.04" />
      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
    </inertial>
  </link>
  <joint name="wheel_mr_spin_joint" type="continuous">
    <parent link="right_bogie_link" />
    <child link="wheel_mr_link" />
    <origin xyz="0 0.060 -0.010" rpy="1.5708 0 0" />
    <axis xyz="0 0 1" />
    <dynamics damping="0.01" friction="0.005" />
  </joint>

  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
  <link name="wheel_rr_steer_link">
    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
    <inertial>
      <mass value="0.005" />
      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
    </inertial>
  </link>
  <joint name="wheel_rr_steer_joint" type="revolute">
    <parent link="right_bogie_link" />
    <child link="wheel_rr_steer_link" />
    <origin xyz="0 -0.060 -0.010" rpy="0 0 0" />
    <axis xyz="0 0 1" />
    <limit lower="-0.6109" upper="0.6109" effort="2.0" velocity="1.5" />
    <dynamics damping="0.01" friction="0.005" />
  </joint>

  <link name="wheel_rr_link">
    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
    <inertial>
      <mass value="0.04" />
      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
    </inertial>
  </link>
  <joint name="wheel_rr_link_spin_joint" type="continuous">
    <parent link="wheel_rr_steer_link" />
    <child link="wheel_rr_link" />
    <origin xyz="0 0 0" rpy="1.5708 0 0" />
    <axis xyz="0 0 1" />
    <dynamics damping="0.01" friction="0.005" />
  </joint>

  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
  <link name="differential_bar_link">
    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
    <inertial>
      <mass value="0.02" />
      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
    </inertial>
  </link>
  <joint name="differential_bar_joint" type="fixed">
    <parent link="chassis" />
    <child link="differential_bar_link" />
    <origin xyz="0 0 0.045" rpy="0 0 0" />
  </joint>

  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
  <link name="lidar_link">
    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
    <inertial><mass value="0.001" />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</inertial>
  </link>
  <joint name="lidar_link_joint" type="fixed">
    <parent link="chassis" />
    <child link="lidar_link" />
    <origin xyz="0 0 -0.015" rpy="0 0 0" />
  </joint>

  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
  <link name="imu_link">
    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
    <inertial><mass value="0.001" />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</inertial>
  </link>
  <joint name="imu_link_joint" type="fixed">
    <parent link="chassis" />
    <child link="imu_link" />
    <origin xyz="0 0 -0.010" rpy="0 0 0" />
  </joint>

  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
  <link name="gps_link">
    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
    <inertial><mass value="0.001" />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</inertial>
  </link>
  <joint name="gps_link_joint" type="fixed">
    <parent link="chassis" />
    <child link="gps_link" />
    <origin xyz="0 -0.100 -0.015" rpy="0 0 0" />
  </joint>
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

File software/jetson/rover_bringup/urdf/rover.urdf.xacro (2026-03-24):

<?xml version="1.0"?>
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
<robot name="mars_rover" xmlns:xacro="http://www.ros.org/wiki/xacro">

  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
  <xacro:property name="body_length" value="0.260" />  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
  <xacro:property name="body_width" value="0.440" />  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
  <xacro:property name="body_height" value="0.080" />  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
  <xacro:property name="body_mass" value="0.45" />
  <xacro:property name="body_z" value="0.100" />  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
  <xacro:property name="wheel_radius" value="0.040" />
  <xacro:property name="wheel_width" value="0.032" />
  <xacro:property name="wheel_mass" value="0.04" />

  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
  <xacro:property name="axle_front_y" value="0.180" />
  <xacro:property name="axle_mid_y" value="0.0" />
  <xacro:property name="axle_rear_y" value="-0.180" />
  <xacro:property name="axle_left_x" value="-0.140" />
  <xacro:property name="axle_right_x" value="0.140" />

  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
  <xacro:property name="rocker_length" value="0.180" />
  <xacro:property name="rocker_width" value="0.020" />
  <xacro:property name="rocker_height" value="0.015" />
  <xacro:property name="rocker_mass" value="0.03" />
  <xacro:property name="rocker_pivot_x" value="0.125" />  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
  <xacro:property name="rocker_pivot_z" value="0.060" />  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
  <xacro:property name="bogie_length" value="0.180" />
  <xacro:property name="bogie_width" value="0.018" />
  <xacro:property name="bogie_height" value="0.012" />
  <xacro:property name="bogie_mass" value="0.02" />
  <xacro:property name="bogie_half" value="0.090" />

  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
  <xacro:property name="diff_bar_length" value="0.300" />
  <xacro:property name="diff_bar_radius" value="0.005" />
  <xacro:property name="diff_bar_mass" value="0.02" />

  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
  <xacro:property name="rocker_limit" value="${15.0 * 3.14159265 / 180.0}" />  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
  <xacro:property name="bogie_limit" value="${20.0 * 3.14159265 / 180.0}" />  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
  <xacro:property name="steer_limit" value="${35.0 * 3.14159265 / 180.0}" />  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
  <xacro:property name="color_body" value="0.192 0.196 0.267 1.0" />  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
  <xacro:property name="color_wheel" value="0.424 0.439 0.525 1.0" />  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
  <xacro:property name="color_arm" value="0.271 0.278 0.353 1.0" />  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
  <xacro:property name="color_sensor" value="0.953 0.545 0.659 1.0" />  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
  <xacro:macro name="box_inertia" params="m x y z">
    <inertial>
      <mass value="${m}" />
      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
    </inertial>
  </xacro:macro>

  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
  <xacro:macro name="cylinder_inertia" params="m r l">
    <inertial>
      <mass value="${m}" />
      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
    </inertial>
  </xacro:macro>

  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
  <xacro:macro name="wheel" params="name parent *origin">
    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
    <link name="${name}">
      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
      <xacro:cylinder_inertia m="${wheel_mass}" r="${wheel_radius}" l="${wheel_width}" />
    </link>

    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
    <joint name="${name}_spin_joint" type="continuous">
      <parent link="${parent}" />
      <child link="${name}" />
      <xacro:insert_block name="origin" />
      <axis xyz="0 0 1" />
      <dynamics damping="0.01" friction="0.005" />
    </joint>
  </xacro:macro>

  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
  <xacro:macro name="steered_wheel" params="prefix parent x_offset y_offset z_offset">
    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
    <link name="${prefix}_steer_link">
      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
      <xacro:cylinder_inertia m="0.005" r="0.008" l="0.020" />
    </link>

    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
    <joint name="${prefix}_steer_joint" type="revolute">
      <parent link="${parent}" />
      <child link="${prefix}_steer_link" />
      <origin xyz="${x_offset} ${y_offset} ${z_offset}" rpy="0 0 0" />
      <axis xyz="0 0 1" />
      <limit lower="${-steer_limit}" upper="${steer_limit}" effort="2.0" velocity="1.5" />
      <dynamics damping="0.01" friction="0.005" />
    </joint>

    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
    <xacro:wheel name="${prefix}_link" parent="${prefix}_steer_link">
      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
      <origin xyz="0 0 0" rpy="${3.14159265/2.0} 0 0" />
    </xacro:wheel>
  </xacro:macro>

  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
  <xacro:macro name="rocker_arm" params="side sign">
    <link name="${side}_rocker_link">
      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
      <xacro:box_inertia m="${rocker_mass}" x="${rocker_width}" y="${rocker_length}" z="${rocker_height}" />
    </link>
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

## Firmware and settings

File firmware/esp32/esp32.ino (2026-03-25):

// ============================================================
// Mars Rover — Phase 1 Firmware
// ESP32-S3 DevKitC-1 (N16R8)
// Version: 0.3.0
//
// Phase 1: 0.4 scale prototype
// - 4-channel motor control (L298N, 6 motors as 4 groups)
// - 4 SG90 steering servos (Ackermann + point turn + crab)
// - WiFi web server + WebSocket for phone control
// - NMEA text UART protocol for Jetson communication (EA-12)
// - Battery monitoring (ADC)
// - 2 wheel encoders (optional)
// - E-stop button
// - Phase 2: define PHASE2_BINARY_PROTOCOL for COBS binary UART (EA-18)
//
// Architecture: Single translation unit (.h includes)
// Same proven pattern as Clock/Lamp ESP8266 projects
//
// See EA-08 for hardware spec, EA-09 for pin map,
// EA-10 for steering geometry, EA-12 for UART protocol (Phase 2)
// ============================================================

#include <WiFi.h>
#include <esp_task_wdt.h>

#include "config.h"
#include "motors.h"
#include "steering.h"
#include "sensors.h"
#include "leds.h"
#include "rover_webserver.h"
#include "ota.h"
#include "uart_nmea.h"
#include "uart_binary.h"

// --- Timing ---
unsigned long lastMotorUpdate = 0;
unsigned long lastSensorUpdate = 0;
unsigned long lastBattUpdate = 0;
unsigned long lastCommandTime = 0;

// --- State ---
bool estopActive = false;
bool wifiConnected = false;
bool roverArmed = false;        // Must be armed before motors accept commands

// ---- Setup ----

void setup() {
  Serial.begin(115200);
  delay(500);

  Serial.println();
  Serial.println("========================================");
  Serial.printf("  Mars Rover Phase 1 — v%s\n", FW_VERSION);
  Serial.println("  ESP32-S3 Motor Controller");
  Serial.println("========================================");

  // Status LED
  pinMode(STATUS_LED_PIN, OUTPUT);
  digitalWrite(STATUS_LED_PIN, LOW);

  // Initialise subsystems
  setupMotors();
  setupSteering();
  setupSensors();

  // Connect WiFi
  connectWiFi();

  // Start web server
  setupWebServer();

  // OTA firmware updates
  setupOTA();

  // Start UART for Jetson communication (Phase 1: NMEA text)
#ifndef PHASE2_BINARY_PROTOCOL
  setupUartNMEA();
#endif

  // Enable watchdog (5 second timeout)
  // ESP32 Arduino Core v3.x uses config struct
  esp_task_wdt_config_t wdt_config = {
    .timeout_ms = WATCHDOG_TIMEOUT_S * 1000,
    .idle_core_mask = 0,
    .trigger_panic = true
  };
  esp_task_wdt_init(&wdt_config);
  esp_task_wdt_add(NULL);  // Add current task

  Serial.println("[MAIN] Setup complete — ready to drive!");
  Serial.printf("[MAIN] Free heap: %d bytes\n", ESP.getFreeHeap());

  lastCommandTime = millis();
}

// ---- Main Loop ----

void loop() {
  unsigned long now = millis();

  // Feed watchdog
  esp_task_wdt_reset();

  // Handle WiFi reconnection (non-blocking)
  static bool wifiReconnecting = false;
  static unsigned long wifiReconnectStart = 0;
  if (WiFi.status() != WL_CONNECTED) {
    if (wifiConnected) {
      Serial.println("[WIFI] Disconnected — attempting reconnect");
      wifiConnected = false;
      stopAllMotors();
    }
    if (!wifiReconnecting) {
      WiFi.mode(WIFI_STA);
      WiFi.begin(WIFI_SSID, WIFI_PASS);
      wifiReconnecting = true;
      wifiReconnectStart = millis();
    } else if (millis() - wifiReconnectStart > WIFI_RECONNECT_INTERVAL_MS) {
      wifiReconnecting = false; // will retry next loop
    }
  } else {
    wifiReconnecting = false;
    if (!wifiConnected) {
      wifiConnected = true;
      String ip = WiFi.localIP().toString();
      Serial.printf("[WIFI] Reconnected! IP: %s\n", ip.c_str());
    }
  }

  // Handle OTA updates
  handleOTA();

  // Handle web server + WebSocket
  handleWeb();

  // Handle UART protocol (Jetson communication)
#ifndef PHASE2_BINARY_PROTOCOL
  handleUartNMEA();
#endif

  // Check E-stop (debounced)
  static unsigned long lastEstopChange = 0;
  bool raw = isEStopPressed();
  if (raw != estopActive && (now - lastEstopChange > 50)) {
    lastEstopChange = now;
    estopActive = raw;
    if (estopActive) {
      stopAllMotors();
      Serial.println("[ESTOP] Activated — all motors stopped");
    } else {
      Serial.println("[ESTOP] Released — ready to drive");
    }
  }

  // Motor speed ramping + steering update (50 Hz)
  if (now - lastMotorUpdate >= MOTOR_UPDATE_MS) {
    if (!estopActive && !batteryCritical && roverArmed) {
      updateMotors();
      updateSteering();
      checkStall(motorSpeed);
    } else if (!roverArmed) {
      // Silently keep motors stopped when not armed
      stopAllMotors();
    }
    lastMotorUpdate = now;
  }

  // Sensor reading (10 Hz)
  if (now - lastSensorUpdate >= SENSOR_UPDATE_MS) {
    // Encoders are interrupt-driven, no polling needed
    lastSensorUpdate = now;
  }

  // Battery monitoring (1 Hz)
  if (now - lastBattUpdate >= BATT_UPDATE_MS) {
    updateBattery();
    lastBattUpdate = now;
  }

  // Command timeout: stop motors if no command received
  // (WebSocket disconnect already stops, but this catches other cases)
  if (now - lastCommandTime > CMD_TIMEOUT_MS && (motorTarget[0] != 0 || motorTarget[1] != 0 || motorTarget[2] != 0 || motorTarget[3] != 0)) {
    stopAllMotors();
    Serial.println("[MAIN] Command timeout — motors stopped");
  }

  // Blink status LED based on state
  updateStatusLED(now);
}

// ---- WiFi Connection ----

void connectWiFi() {
  if (WiFi.status() == WL_CONNECTED) {
    wifiConnected = true;
    return;
  }

  Serial.printf("[WIFI] Connecting to %s", WIFI_SSID);
  WiFi.mode(WIFI_STA);
  WiFi.setHostname(WIFI_HOSTNAME);
  WiFi.begin(WIFI_SSID, WIFI_PASS);

  unsigned long start = millis();
  while (WiFi.status() != WL_CONNECTED && millis() - start < WIFI_CONNECT_TIMEOUT_MS) {
    delay(500);
    Serial.print(".");
    esp_task_wdt_reset();
  }

  if (WiFi.status() == WL_CONNECTED) {
    wifiConnected = true;
    String ip = WiFi.localIP().toString();
    Serial.printf("\n[WIFI] Connected! IP: %s\n", ip.c_str());
    Serial.printf("[WIFI] Open http://%s in browser\n", ip.c_str());
  } else {
    Serial.println("\n[WIFI] Connection failed — will retry");
  }
}

// ---- Status LED ----

// LED Patterns (5 distinct states, EA-22 DFT-07):
//   Idle (not armed):  Slow pulse (1s on, 1s off)
//   Armed (ready):     Double blink (2 quick flashes, pause)
//   Driving (active):  Solid on
//   Warning (battery): Fast blink (250ms)
//   Error (E-stop/critical): SOS pattern (3 short, 3 long, 3 short)
void updateStatusLED(unsigned long now) {
  if (estopActive) {
    // SOS pattern: 3 short (100ms), 3 long (300ms), 3 short (100ms)
    int cycle = (now % 3000);
    bool on = false;
    if (cycle < 300) on = (cycle / 100) % 2 == 0;           // 3 short
    else if (cycle < 600) on = false;                         // gap
    else if (cycle < 1500) on = ((cycle - 600) / 300) % 2 == 0;  // 3 long
    else if (cycle < 1800) on = false;                        // gap
    else if (cycle < 2100) on = ((cycle - 1800) / 100) % 2 == 0; // 3 short
    else on = false;                                          // pause
    digitalWrite(STATUS_LED_PIN, on ? HIGH : LOW);
  } else if (batteryCritical) {
    // Very fast blink — error state
    digitalWrite(STATUS_LED_PIN, (now / 100) % 2);
  } else if (batteryWarning) {
    // Fast blink — warning
    digitalWrite(STATUS_LED_PIN, (now / 250) % 2);
  } else if (stallDetected) {
    // Triple quick blink — stall warning
    int phase = (now / 120) % 8;
    digitalWrite(STATUS_LED_PIN, (phase < 6 && phase % 2 == 0) ? HIGH : LOW);
  } else if (!wifiConnected) {
    // Double blink — WiFi connecting
    int phase = (now / 150) % 6;
    digitalWrite(STATUS_LED_PIN, (phase == 0 || phase == 2) ? HIGH : LOW);
  } else if (!roverArmed) {
    // Slow pulse — idle, waiting for arm command
    digitalWrite(STATUS_LED_PIN, (now / 1000) % 2);
  } else if (motorTarget[0] != 0 || motorTarget[1] != 0 ||
             motorTarget[2] != 0 || motorTarget[3] != 0) {
    // Solid on — actively driving
    digitalWrite(STATUS_LED_PIN, HIGH);
  } else {
    // Armed, connected, idle — double blink (ready)
    int phase = (now / 200) % 6;
    digitalWrite(STATUS_LED_PIN, (phase == 0 || phase == 2) ? HIGH : LOW);
  }
}

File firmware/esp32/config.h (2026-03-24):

#ifndef CONFIG_H
#define CONFIG_H

// ============================================================
// Mars Rover Phase 1 — Configuration
// ESP32-S3 DevKitC-1 (N16R8)
// Version: 0.3.0
// See EA-09 for full GPIO pin map
// ============================================================

// --- Firmware Version ---
#define FW_VERSION "0.3.0"
#define FW_NAME "MarsRover-P1"

// --- WiFi ---
#define WIFI_SSID "VM9388584"
#define WIFI_PASS ""  // Set before upload
#define WIFI_HOSTNAME "rover"
#define WIFI_CONNECT_TIMEOUT_MS 15000
#define WIFI_RECONNECT_INTERVAL_MS 5000
#define WEB_SERVER_PORT 80
#define WS_PORT 81

// --- Motor Pins (L298N, 4-channel: 2 per side) ---
// Left front motor (W1)
#define MOTOR_LF_PWM  4   // LEDC Ch0
#define MOTOR_LF_IN1  5
#define MOTOR_LF_IN2  6

// Left mid+rear motors (W2+W3 in parallel)
#define MOTOR_LR_PWM  7   // LEDC Ch1
#define MOTOR_LR_IN1  15
#define MOTOR_LR_IN2  16

// Right front motor (W6)
#define MOTOR_RF_PWM  8   // LEDC Ch2
#define MOTOR_RF_IN1  9
#define MOTOR_RF_IN2  10

// Right mid+rear motors (W5+W4 in parallel)
#define MOTOR_RR_PWM  11  // LEDC Ch3
#define MOTOR_RR_IN1  12
#define MOTOR_RR_IN2  13

// --- Motor PWM Config ---
#define MOTOR_PWM_FREQ     1000   // 1 kHz for L298N
#define MOTOR_PWM_RES      8      // 8-bit (0-255)
#define MOTOR_LEDC_CH_LF   0
#define MOTOR_LEDC_CH_LR   1
#define MOTOR_LEDC_CH_RF   2
#define MOTOR_LEDC_CH_RR   3
#define MOTOR_LEDC_TIMER   0

// --- Servo Pins (SG90, direct PWM) ---
#define SERVO_FL_PIN  1    // LEDC Ch4
#define SERVO_FR_PIN  2    // LEDC Ch5
#define SERVO_RL_PIN  41   // LEDC Ch6
#define SERVO_RR_PIN  42   // LEDC Ch7

// --- Servo PWM Config ---
#define SERVO_PWM_FREQ     50     // 50 Hz standard servo
#define SERVO_PWM_RES      16     // 16-bit for precise pulse width
#define SERVO_LEDC_CH_FL   4
#define SERVO_LEDC_CH_FR   5
#define SERVO_LEDC_CH_RL   6
#define SERVO_LEDC_CH_RR   7
#define SERVO_LEDC_TIMER   1

// Servo pulse widths (microseconds)
#define SERVO_MIN_US    544      // SG90 safe minimum (was 500)
#define SERVO_MAX_US    2400
#define SERVO_CENTER_US 1500
#define SERVO_US_PER_DEG 10.31f  // (2400-544)/180

// Steering limits (degrees)
#define STEER_MAX_ANGLE   35.0f
#define STEER_DEADBAND    1.0f
#define STEER_MAX_RATE    60.0f   // degrees per second

// --- Encoder Pins (optional, 2 wheels for Phase 1) ---
#define ENC_W1_CHA  38
#define ENC_W1_CHB  39
#define ENC_W6_CHA  40
#define ENC_W6_CHB  48

// --- Battery Monitoring ---
#define BATT_ADC_PIN  14
#define BATT_CELLS    2          // 2S LiPo
#define BATT_FULL_V   8.4f      // 4.2V per cell × 2
#define BATT_NOMINAL_V 7.4f
#define BATT_WARN_V   7.0f      // 3.5V per cell
#define BATT_CUTOFF_V  6.4f     // 3.2V per cell
#define BATT_DIVIDER_RATIO 3.128f  // (10k + 4.7k) / 4.7k — see EA-09

// --- Status LED ---
#define STATUS_LED_PIN  0

// --- E-Stop Button ---
#define ESTOP_PIN  46   // Input-only pin, internal pull-down

// --- Rover Geometry (0.4 scale, millimetres) ---
#define WHEELBASE_MM    360.0f   // Front to rear axle
#define TRACK_WIDTH_MM  280.0f   // Wheel centre to centre
#define HALF_TRACK_MM   140.0f   // Track / 2
#define L_FM_MM         180.0f   // Front to middle axle
#define L_MR_MM         180.0f   // Middle to rear axle
#define WHEEL_RADIUS_MM  40.0f   // 80mm diameter / 2
#define MIN_TURN_RADIUS  397.0f  // See EA-10

// --- Timing ---
#define MOTOR_UPDATE_MS   20     // 50 Hz motor control loop
#define SENSOR_UPDATE_MS  100    // 10 Hz sensor reading
#define BATT_UPDATE_MS    1000   // 1 Hz battery check
#define WS_UPDATE_MS      200    // 5 Hz WebSocket status broadcast
#define WATCHDOG_TIMEOUT_S  5    // Watchdog timer (seconds)

// --- Safety ---
#define SPEED_LIMIT_PCT  100     // Max motor speed (0-100%)
#define RAMP_RATE        10      // Max speed change per update (% per tick)
#define CMD_TIMEOUT_MS   2000    // Motor safety timeout (no command = stop)
#define ARM_REQUIRED     true    // Require ARM command before accepting motor commands
#define BATT_WARN_SPEED_PCT 50   // Speed limit when battery warning (percent of normal)
#define BATT_CRIT_SPEED_PCT 0    // Speed limit at critical battery (full stop)
#define STALL_DETECT_MS  2000    // If encoder unchanged for this long at PWM>20%, trigger stall
#define STALL_PWM_THRESH 51      // PWM duty above which stall is checked (20% of 255)

// --- Arm Servo Pin Reserves (Phase 2 robotic arm, EA-24) ---
// #define ARM_SHOULDER_PIN 3   // Reserved for Phase 2 arm shoulder servo
// #define ARM_ELBOW_PIN    17  // Reserved for Phase 2 arm elbow servo

// --- Ackermann Turn Presets (used by WebSocket commands) ---
#define TURN_RADIUS_WIDE_MM    1500.0f  // Normal Ackermann turn
#define TURN_RADIUS_TIGHT_MM   1000.0f  // Tight Ackermann turn
#define TURN_INNER_SPEED_WIDE  0.83f    // Inner wheel ratio: (1500-140)/(1500+140) = 0.829
#define TURN_INNER_SPEED_TIGHT 0.75f    // Inner wheel ratio: (1000-140)/(1000+140) = 0.754
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

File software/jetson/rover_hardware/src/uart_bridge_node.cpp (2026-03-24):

#include "rover_hardware/uart_bridge.hpp"

#include <fcntl.h>
#include <termios.h>
#include <unistd.h>
#include <cstring>
#include <sstream>
#include <vector>
#include <algorithm>
#include <cmath>

namespace rover_hardware
{

constexpr const char * UartBridgeNode::JOINT_NAMES[];
constexpr const char * UartBridgeNode::US_FRAME_NAMES[];

UartBridgeNode::UartBridgeNode(const rclcpp::NodeOptions & options)
: Node("uart_bridge", options),
  serial_fd_(-1),
  estop_active_(false)
{
  // Declare parameters
  this->declare_parameter("serial_port", "/dev/ttyTHS1");
  this->declare_parameter("baud_rate", 115200);
  this->declare_parameter("command_rate_hz", 50);
  this->declare_parameter("watchdog_timeout_ms", 200);
  this->declare_parameter("ping_interval_ms", 1000);

  serial_port_ = this->get_parameter("serial_port").as_string();
  baud_rate_ = this->get_parameter("baud_rate").as_int();
  command_rate_hz_ = this->get_parameter("command_rate_hz").as_int();
  int watchdog_ms = this->get_parameter("watchdog_timeout_ms").as_int();
  int ping_ms = this->get_parameter("ping_interval_ms").as_int();

  RCLCPP_INFO(this->get_logger(), "UART Bridge starting on %s @ %d baud",
    serial_port_.c_str(), baud_rate_);

  // Publishers
  encoder_pub_ = this->create_publisher<sensor_msgs::msg::JointState>(
    "/encoders", 10);
  imu_pub_ = this->create_publisher<sensor_msgs::msg::Imu>(
    "/imu/data", 10);
  odom_pub_ = this->create_publisher<nav_msgs::msg::Odometry>(
    "/wheel_odom", 10);
  battery_pub_ = this->create_publisher<sensor_msgs::msg::BatteryState>(
    "/battery", 10);
  status_pub_ = this->create_publisher<rover_msgs::msg::RoverStatus>(
    "/rover/status", 10);

  // Ultrasonic publishers (6 sensors)
  for (int i = 0; i < 6; i++) {
    char topic[64];
    snprintf(topic, sizeof(topic), "/ultrasonic/%d", i);
    ultrasonic_pubs_[i] = this->create_publisher<sensor_msgs::msg::Range>(topic, 10);
  }

  // Subscribers
  wheel_speeds_sub_ = this->create_subscription<rover_msgs::msg::WheelSpeeds>(
    "/wheel_speeds", 10,
    std::bind(&UartBridgeNode::wheel_speeds_callback, this, std::placeholders::_1));
  steering_sub_ = this->create_subscription<rover_msgs::msg::SteeringAngles>(
    "/steering_angles", 10,
    std::bind(&UartBridgeNode::steering_angles_callback, this, std::placeholders::_1));
  estop_sub_ = this->create_subscription<std_msgs::msg::Bool>(
    "/estop", 10,
    std::bind(&UartBridgeNode::estop_callback, this, std::placeholders::_1));
  arm_sub_ = this->create_subscription<std_msgs::msg::Bool>(
    "/rover/arm", 10,
    std::bind(&UartBridgeNode::arm_callback, this, std::placeholders::_1));

  // Open serial port
  if (!open_serial()) {
    RCLCPP_ERROR(this->get_logger(), "Failed to open serial port %s", serial_port_.c_str());
    RCLCPP_WARN(this->get_logger(), "Running in MOCK mode - no serial communication");
  }

  // Timers
  // Read serial at 200Hz (5ms) to keep buffer clear
  serial_read_timer_ = this->create_wall_timer(
    std::chrono::milliseconds(5),
    std::bind(&UartBridgeNode::serial_read_callback, this));

  // Ping ESP32 periodically
  ping_timer_ = this->create_wall_timer(
    std::chrono::milliseconds(ping_ms),
    std::bind(&UartBridgeNode::ping_callback, this));

  // Watchdog: send stop if no commands received recently
  watchdog_timer_ = this->create_wall_timer(
    std::chrono::milliseconds(watchdog_ms),
    std::bind(&UartBridgeNode::watchdog_callback, this));

  last_cmd_time_.store(this->now());
  last_esp_time_.store(this->now());

  RCLCPP_INFO(this->get_logger(), "UART Bridge node initialized (%d Hz command rate)",
    command_rate_hz_);
}

UartBridgeNode::~UartBridgeNode()
{
  // Send stop command before shutting down
  write_serial(format_nmea("STP", "0"));
  close_serial();
}

bool UartBridgeNode::open_serial()
{
  std::lock_guard<std::mutex> lock(serial_mutex_);

  serial_fd_ = open(serial_port_.c_str(), O_RDWR | O_NOCTTY | O_NONBLOCK);
  if (serial_fd_ < 0) {
    RCLCPP_ERROR(this->get_logger(), "open(%s) failed: %s",
      serial_port_.c_str(), strerror(errno));
    return false;
  }

  struct termios tty;
  memset(&tty, 0, sizeof(tty));

  if (tcgetattr(serial_fd_, &tty) != 0) {
    RCLCPP_ERROR(this->get_logger(), "tcgetattr failed: %s", strerror(errno));
    close(serial_fd_);
    serial_fd_ = -1;
    return false;
  }

  // Set baud rate
  speed_t baud;
  switch (baud_rate_) {
    case 9600: baud = B9600; break;
    case 19200: baud = B19200; break;
    case 38400: baud = B38400; break;
    case 57600: baud = B57600; break;
    case 115200: baud = B115200; break;
    default:
      RCLCPP_ERROR(this->get_logger(), "Unsupported baud rate: %d", baud_rate_);
      close(serial_fd_);
      serial_fd_ = -1;
      return false;
  }

  cfsetispeed(&tty, baud);
  cfsetospeed(&tty, baud);

  // 8N1 configuration
  tty.c_cflag &= ~PARENB;   // No parity
  tty.c_cflag &= ~CSTOPB;   // 1 stop bit
  tty.c_cflag &= ~CSIZE;
  tty.c_cflag |= CS8;        // 8 data bits
  tty.c_cflag &= ~CRTSCTS;  // No hardware flow control
  tty.c_cflag |= CREAD | CLOCAL;  // Enable receiver, ignore modem controls

  // Raw input mode
  tty.c_lflag &= ~(ICANON | ECHO | ECHOE | ISIG);
  tty.c_iflag &= ~(IXON | IXOFF | IXANY);
  tty.c_iflag &= ~(IGNBRK | BRKINT | PARMRK | ISTRIP | INLCR | IGNCR | ICRNL);

  // Raw output mode
  tty.c_oflag &= ~OPOST;

  // Non-blocking read
  tty.c_cc[VMIN] = 0;
  tty.c_cc[VTIME] = 0;

  if (tcsetattr(serial_fd_, TCSANOW, &tty) != 0) {
    RCLCPP_ERROR(this->get_logger(), "tcsetattr failed: %s", strerror(errno));
    close(serial_fd_);
    serial_fd_ = -1;
    return false;
  }

  // Flush any existing data
  tcflush(serial_fd_, TCIOFLUSH);

  RCLCPP_INFO(this->get_logger(), "Serial port %s opened successfully", serial_port_.c_str());
  return true;
}

void UartBridgeNode::close_serial()
{
  std::lock_guard<std::mutex> lock(serial_mutex_);
  if (serial_fd_ >= 0) {
    close(serial_fd_);
    serial_fd_ = -1;
  }
}

bool UartBridgeNode::write_serial(const std::string & data)
{
  std::lock_guard<std::mutex> lock(serial_mutex_);
  if (serial_fd_ < 0) {
    return false;
  }

  ssize_t written = write(serial_fd_, data.c_str(), data.size());
  if (written < 0) {
    RCLCPP_WARN(this->get_logger(), "Serial write failed: %s", strerror(errno));
    return false;
  }
  return written == static_cast<ssize_t>(data.size());
}
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

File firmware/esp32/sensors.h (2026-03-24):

#ifndef SENSORS_H
#define SENSORS_H

// ============================================================
// Sensor reading — battery voltage, encoders (optional)
// Phase 1: ADC battery monitor + 2 wheel encoders
// ============================================================

// Forward declarations
float readBatteryRaw();

// --- Battery ---
float batteryVoltage = 0;
uint8_t batteryPercent = 100;
bool batteryWarning = false;
bool batteryCritical = false;

// ADC smoothing
#define BATT_SAMPLES 10
float battSamples[BATT_SAMPLES];
uint8_t battSampleIdx = 0;
bool battSamplesFull = false;

// --- Battery-based speed limiting ---
uint8_t batterySpeedLimit = 100;  // Max speed percent based on battery state

// --- Stall detection ---
bool stallDetected = false;
int32_t lastEncoderSnapshot[2] = {0, 0};
unsigned long stallCheckStart = 0;

// --- Encoders ---
volatile int32_t encoderCount[2] = {0, 0};  // W1, W6

void IRAM_ATTR encoderISR_W1() {
  // Simple counting — direction from channel B
  if (digitalRead(ENC_W1_CHB)) {
    encoderCount[0]++;
  } else {
    encoderCount[0]--;
  }
}

void IRAM_ATTR encoderISR_W6() {
  if (digitalRead(ENC_W6_CHB)) {
    encoderCount[1]++;
  } else {
    encoderCount[1]--;
  }
}

void setupSensors() {
  // Battery ADC
  analogReadResolution(12);  // 12-bit ADC (0-4095)
  analogSetPinAttenuation(BATT_ADC_PIN, ADC_11db);  // Full 0-3.3V range
  pinMode(BATT_ADC_PIN, INPUT);

  // Fill battery samples with initial reading
  float initial = readBatteryRaw();
  for (int i = 0; i < BATT_SAMPLES; i++) {
    battSamples[i] = initial;
  }
  battSamplesFull = true;

  // Encoders (optional — skip if pins not connected)
  pinMode(ENC_W1_CHA, INPUT_PULLUP);
  pinMode(ENC_W1_CHB, INPUT_PULLUP);
  pinMode(ENC_W6_CHA, INPUT_PULLUP);
  pinMode(ENC_W6_CHB, INPUT_PULLUP);

  attachInterrupt(ENC_W1_CHA, encoderISR_W1, RISING);
  attachInterrupt(ENC_W6_CHA, encoderISR_W6, RISING);

  // E-stop button
  pinMode(ESTOP_PIN, INPUT);  // GPIO46 has internal pull-down

  Serial.println("[SENSOR] Initialised (ADC + 2 encoders + E-stop)");
}

float readBatteryRaw() {
  int raw = analogRead(BATT_ADC_PIN);
  float voltage = (raw / 4095.0f) * 3.3f;  // ADC to voltage
  return voltage * BATT_DIVIDER_RATIO;       // Scale up through divider
}

void updateBattery() {
  // Moving average filter
  battSamples[battSampleIdx] = readBatteryRaw();
  battSampleIdx = (battSampleIdx + 1) % BATT_SAMPLES;

  // Calculate average
  float sum = 0;
  for (int i = 0; i < BATT_SAMPLES; i++) {
    sum += battSamples[i];
  }
  batteryVoltage = sum / BATT_SAMPLES;

  // Calculate percentage (linear approximation: 6.4V=0%, 8.4V=100%)
  int pct = (int)((batteryVoltage - BATT_CUTOFF_V) / (BATT_FULL_V - BATT_CUTOFF_V) * 100.0f);
  batteryPercent = constrain(pct, 0, 100);

  // Warnings
  batteryWarning = (batteryVoltage <= BATT_WARN_V);
  batteryCritical = (batteryVoltage <= BATT_CUTOFF_V);

  // Battery-based speed limiting (EA-22 FR-06)
  if (batteryCritical) {
    batterySpeedLimit = BATT_CRIT_SPEED_PCT;
    stopAllMotors();
    Serial.println("[BATT] CRITICAL — motors stopped!");
  } else if (batteryWarning) {
    batterySpeedLimit = BATT_WARN_SPEED_PCT;
    Serial.println("[BATT] Warning — speed limited to 50%");
  } else {
    batterySpeedLimit = 100;
  }
}

// --- Stall Detection (EA-22 FR-06) ---
// If encoders show no motion while PWM is above threshold, motor is stalled
void checkStall(int8_t* motorCurrent) {
  // Only check if motors are actually being driven
  bool motorsRunning = false;
  for (int i = 0; i < 4; i++) {
    if (abs(motorCurrent[i]) > (STALL_PWM_THRESH * 100 / 255)) {
      motorsRunning = true;
      break;
    }
  }

  if (!motorsRunning) {
    stallDetected = false;
    stallCheckStart = millis();
    lastEncoderSnapshot[0] = encoderCount[0];
    lastEncoderSnapshot[1] = encoderCount[1];
    return;
  }

  // Check if encoders have changed
  noInterrupts();
  int32_t c0 = encoderCount[0];
  int32_t c1 = encoderCount[1];
  interrupts();

  if (c0 != lastEncoderSnapshot[0] || c1 != lastEncoderSnapshot[1]) {
    // Movement detected — reset stall timer
    stallCheckStart = millis();
    lastEncoderSnapshot[0] = c0;
    lastEncoderSnapshot[1] = c1;
    stallDetected = false;
    return;
  }

  // No movement — check timeout
  if (millis() - stallCheckStart >= STALL_DETECT_MS) {
    if (!stallDetected) {
      stallDetected = true;
      Serial.println("[STALL] Motor stall detected — reducing power");
    }
  }
}

bool isEStopPressed() {
  return digitalRead(ESTOP_PIN) == HIGH;
}

// Get encoder counts and reset (for odometry)
void getAndResetEncoders(int32_t* w1, int32_t* w6) {
  noInterrupts();
  *w1 = encoderCount[0];
  *w6 = encoderCount[1];
  encoderCount[0] = 0;
  encoderCount[1] = 0;
  interrupts();
}

#endif // SENSORS_H

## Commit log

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2026-03-15 Add 7 engineering analysis documents and update design doc to v1.1
    Engineering analyses (EA-01 through EA-07) provide dissertation-grade
    research, calculations, and trade-off analyses for all rover subsystems:
    - EA-01: Rocker-bogie suspension (NASA ratio scaling, stability analysis)
    - EA-02: Drivetrain (torque calcs, Chihai 37mm motor selection)
    - EA-03: Power system (6S LiPo, 97.5W typical, 4hr runtime)
    - EA-04: Compute & sensors (Jetson Orin Nano Super, PCA9685 solution)
    - EA-05: Weight budget (16.7kg Phase 2, 20.8kg Phase 3)
    - EA-06: Cost breakdown ($1,933.75 total, within budget)
    - EA-07: Open source rover review (Sawppy+JPL hybrid approach)
    Design doc updated from v1.0 to v1.1 with all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
2026-03-15 Add EA-13 through EA-15: ROS2 architecture, weatherproofing, safety
    Three additional engineering documents:
    - EA-13: ROS2 software architecture — complete node graph, Nav2
    configuration, SLAM + EKF sensor fusion, YOLO AI pipeline,
    behaviour trees, launch files, resource usage estimates
    - EA-14: Weatherproofing strategy — IP44 Phase 2 / IP54 Phase 3,
    3-zone protection model, cable gland schedule, thermal management,
    corrosion prevention, seasonal maintenance
    - EA-15: Safety systems — 4-layer defence (hardware/firmware/
    software/operational), fault classification and recovery, human
    detection, geofence, anti-theft, ESP32/Jetson crash recovery
    Design doc updated to v1.2 with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
2026-03-15 Add motor noise suppression caps and L298N logic level note to build guide
    - 100nF ceramic capacitors across each N20 motor terminal (noise suppression)
    - Note about L298N 5V logic vs ESP32-S3 3.3V output (works but out of spec)
    - Added capacitors to parts list
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2026-03-15 Add EA-18: Binary UART protocol upgrade for Phase 2
    COBS framing + CRC-16/CCITT at 460800 baud replaces text NMEA
    for production use. 12% bandwidth utilisation (vs 72%), ~1.6ms
    round-trip (vs 7.7ms), stronger error detection, no float on ESP32.
    EA-12 remains Phase 1/debug reference.
2026-03-15 Update EA-11 with community data, add 3D printing reference doc
    Added curved spoke patterns, TPU interference fit dimensions,
    Sawppy/ExoMy benchmarks. Reference doc from research agent adds
    detailed Ender 3 tips and segmentation strategy.
2026-03-15 Update EA-11 with reinforcement options, add materials research ref
    Added carbon fiber/fiberglass reinforcement for Phase 2 arms, UV
    protection layered workflow, slicer modifier mesh tip for inserts,
    and CNC Kitchen strength test data reference document.
2026-03-15 Fix EA-13 Nav2 config, add ROS2 architecture research
    Critical fixes:
    - DWB → RegulatedPurePursuit (DWB generates impossible spin commands)
    - Added use_rotate_to_heading: false (Ackermann can't spin in place)
    - Removed nav2_spin recovery behavior
    - DUBIN motion model (forward-only, not REEDS_SHEPP)
    - Dual EKF (local smooth + global with GPS)
    - USB camera tiered bandwidth management with lifecycle nodes
    - Added reference doc with full configs and launch examples
2026-03-15 Fix Nav2/EKF configs, update design doc to v1.3, add master todo list
    - nav2_params.yaml: DWBLocalPlanner → RegulatedPurePursuit (Ackermann-safe)
    - nav2_params.yaml: REEDS_SHEPP → DUBIN, removed spin recovery behavior
    - ekf.yaml: Single EKF → dual EKF (local odom + global map with GPS)
    - ekf.yaml: Added navsat_transform configuration for GPS conversion
    - nav.launch.py: Updated to launch dual EKF + navsat_transform nodes
    - hardware.launch.py: Replaced inline placeholder URDF with real xacro file
    - Design doc v1.2 → v1.3: Updated EA refs, protocol, node graph
    - Added comprehensive master todo list (~180 tasks across 10 categories)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
    [ekf.yaml]
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2026-03-15 Fix cross-reference inconsistencies across EA-02, EA-05, EA-06
    - EA-02: Fix Ackermann wheelbase from 680mm (projected) to 900mm (axle-to-axle)
    Recalculate turning radius values using correct wheelbase
    - EA-05: Fix motor name from JGB37-520 to Chihai CHR-GM37-520 (185g, matching EA-02)
    Fix motor driver from BTS7960 to Cytron MDD10A (matching EA-02)
    Fix subsystem numbering gap (was 6→8, now sequential)
    - EA-06: Update Phase 1 filament from 500g/$10 to 1kg PETG/$20 (matching EA-08/EA-17)
    - todo-master.md: Mark EA-19 and shopping list as complete
    Issues identified by automated cross-reference audit of all 19 EAs.
2026-03-15 Update todo-master: mark cross-reference audit as complete
    All 8 audit checks performed. 3 HIGH issues fixed (EA-02 wheelbase,
    EA-05 motor/driver names, EA-06 filament cost). 1 gap noted (EA-09
    Phase 2 sensor GPIOs need I2C expander).
2026-03-15 Add master handbook, Gazebo world, BT missions, test procedures, CAD prep, fix firmware compile
    New documents:
    - EA-00: Master Engineering Handbook (compiles all 19 EAs)
    - EA-20: CAD Preparation Guide (Fusion 360 dimensions from EA-08)
    - EA-21: Test Procedures & Acceptance Criteria
    - Design methodology document (V-model, phases, review gates)
    - Fusion 360 MCP setup guide
    - Datasheets README with download links
    - Parametric CAD generation script (generate_rover_params.py)
    New code:
    - Gazebo garden world (slopes, obstacles, gravel paths, furniture)
    - 4 BT.CPP behaviour tree XML missions (patrol, explore, return home, safety)
    - simulation.launch.py defaults to garden world
    Firmware fixes (ESP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
    [esp32.ino, generate_rover_params.py, rover_webserver.h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]
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2026-03-15 Update CLAUDE.md: EA count, fix webserver.h reference, remove duplicate EA-19
    - EA range corrected to EA-00 through EA-21 (was EA-01 through EA-19)
    - Added EA-20 (CAD Preparation) and EA-21 (Test Procedures) to table
    - Fixed rover_webserver.h reference (was webserver.h, renamed earlier)
    - Removed duplicate 19-wiring-diagram.md (keeping 19-phase1-wiring.md)
2026-03-15 Update README.md: correct EA count, fix file references, add missing EAs
    - EA count: 18 → 22 (EA-00 through EA-21)
    - Fixed webserver.h → rover_webserver.h
    - Added ota.h, uart_nmea.h, uart_binary.h to file tree
    - Added EA-00, EA-19, EA-20, EA-21 to engineering analysis table
2026-03-15 Fix stale webserver.h references, update firmware README to v0.2.0
    - Renamed webserver.h → rover_webserver.h in firmware README and EA-16
    - Added ota.h, uart_nmea.h, uart_binary.h to firmware README file list
    - Updated firmware version 0.1.0 → 0.2.0
    - Updated Phase 2 UART reference to EA-18 binary protocol
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2026-03-15 Add Gazebo simulation research: Ackermann plugin, sensor configs, terrain, gotchas
    Covers gazebo_ros_ackermann_drive setup, sensor simulation for RPLidar/OAK-D/
    IMU/GPS/ultrasonics, heightmap terrain with friction zones, Nav2 testing
    methodology, and known issues with Gazebo Classic + ROS 2 Humble.
2026-03-15 Add live camera streaming to PWA: MJPEG feed, source selector, snapshot button
    - Camera feed shows MJPEG stream from Jetson web_server_node (port 8080)
    - Source selector: Front, Rear, Mast, Depth (OAK-D) cameras
    - Stream toggle button with active state styling
    - Snapshot action button (replaces disabled Camera placeholder)
    - Auto-stops stream on WebSocket disconnect
    - Error handling: falls back to placeholder on stream loss
    - Works in both Mocha (dark) and Latte (light) themes
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2026-03-15 Add Gazebo simulation test suite: 21 scenarios with test runner
    - sim_test_scenarios.yaml: 21 structured test scenarios across 7 categories
    (mobility, obstacle avoidance, sensors, navigation, terrain, safety, localization)
    - sim_test_runner.py: executes scenarios against live Gazebo, validates YAML offline
    - Categories: drive/reverse/turn, obstacle stop, LiDAR/IMU/GPS/depth checks,
    Nav2 waypoints, slope climbing, geofence enforcement, TF tree validation
    - Update todo-master: mark firmware tests and sim test suite complete
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2026-03-15 Add UART bridge integration tests: 30 tests for NMEA protocol round-trip
    - NMEACodec: encode/decode with checksum verification
    - UARTBridgeParser: ENC, IMU, BAT, USS, STS message parsing
    - CommandEncoder: CMTR, CSTR, CESP, CCFG command generation
    - OdometryCalculator: differential drive pose from encoder ticks
    (straight, reverse, turns, point turn, cumulative, square path)
    - Stream processing: multi-message bursts, corruption detection, 50Hz telemetry
    - All tests run without ROS2 or hardware
2026-03-15 Consolidate research findings into engineering analyses
    EA-04: Add TensorRT deployment section (FP16 export pipeline, gotchas, benchmarks)
    EA-09: Add Phase 2+ GPIO expansion strategy (PCA9535 expander, I2C address map)
    EA-11: Fix insert pull-out strength, add hole sizing per orientation, UV protection details
    EA-13: Add dual EKF explanation, udev camera rules, use_sim_time warning
2026-03-15 Audit fixes: safety, security, docs consistency across firmware, ROS2, PWA
    Firmware (13 fixes):
    - Non-blocking WiFi reconnect in loop (was blocking 15s, freezing motors)
    - Motor ramp int8_t overflow fix (prevented sudden reversal)
    - Servo trim applied before constrain (prevented servo damage)
    - lastCommandTime updated by WebSocket and UART commands
    - Battery percent: int cast before constrain (prevented uint8_t wrap)
    - E-stop debounce (50ms), command timeout checks all 4 channels
    - Remove PROGMEM/pgm_read_word (no-op on ESP32-S3)
    - Web UI: innerHTML to safe DOM methods
    - Pin-specific ADC attenuation, integer math in setDrive
    - COBS trailing zero removal made robust
    ROS2 (10 fixes):
    - Add mi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
    [rover.urdf.xacro]
2026-03-15 Second-pass audit fixes: COBS, odometry, geofence, patrol, safety
    Firmware (6 fixes):
    - COBS decoder: remove trailing-zero stripping (encoder/decoder asymmetry)
    - setRxBufferSize before Serial1.begin() (was no-op after begin)
    - OTA progress: guard total==0 division
    - RSM command: update lastCommandTime on e-stop resume
    - WiFi reconnect: add WiFi.mode(WIFI_STA) before begin
    - handleStatus: check snprintf return for buffer overflow
    ROS2 (9 fixes):
    - compute_odometry: document mutex requirement
    - Waypoint patrol: fix off-by-two at boundaries (clamp not bounce)
    - Geofence: publish estop+violation continuously while breached
    - WebSocket: protect len(ws_clients) with lock
    - MissionPlanner: subscr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
    [ekf.yaml, esp32.ino, rover_webserver.h]
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2026-03-24 Add EA-26: Complete suspension & wheel system design package
    18-section engineering-grade design document covering:
    - Full component breakdown (wheel modules, rocker, bogie, differential)
    - Differential mechanism types (bar+link vs bevel gear vs spur gear)
    - Key insight: diff links need BALL JOINTS, not simple pins
    - Parametric geometry ratios from NASA Curiosity scaling
    - Joint kinematics, DOF map, articulation limits
    - Bearing/shaft selection for Phase 1 and Phase 2
    - Cable routing with calculated service loop lengths
    - Structural load paths and failure modes
    - CAD assembly order and complete parts checklist
    - 20-parameter design-driving variable list
    - Minimum viable vs high-fidelity CAD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
2026-03-24 Rewrite suspension assembly with full EA-26 differential linkage
    Complete architecture rewrite — no longer just tubes with a straight
    bar. Now includes:
    - Differential bar with central PIVOT point (rotates about X)
    - 2x differential LINKS with ball joints (Heim joints) connecting
    bar ends to rocker arms — this is the key mechanism that was missing
    - Body reference outline with rocker pivot mount bosses
    - Steering knuckles with vertical pivot shafts at steered wheels
    - Servo and motor envelopes at correct positions
    - Bogie pivot connectors with bearing markers
    All geometry is pure primitives (cylinders, spheres, boxes) — runs
    immediately with ZERO STL dependencies. Serves as spatial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
2026-03-24 EA-26 computed dims, shopping list update, assembly enhancements
    - EA-26 Section 9.5: Added computed differential link dimensions table
    (link length 85mm/212mm, angle 28.1°, positions, motion ratio)
    - Shopping list: Added M3 rod-end bearings (x4), updated rod lengths,
    corrected bearing count (9 not 11)
    - Suspension assembly: Added body cross-member, hard stops on rocker
    and bogie pivots, steering bearing bosses, service loop zones,
    parametric body/servo dimensions
2026-03-24 Comprehensive audit fix: 26 files, ~80 findings across 6 audits
    CAD script dimensional fixes:
    - bogie_pivot_connector: pivot bore 8.2mm -> 8.0mm (shaft, not tube socket)
    - differential_pivot_housing: 40x40x25 -> 30x30x20mm (Phase 1 params)
    - servo_mount: M2 hole 2.4mm -> 2.2mm (correct clearance)
    - rover_wheel_v3 hub OD: params reconciled to 14mm (matches V3 CAD)
    generate_rover_params.py:
    - Bearing count comment: 11 -> 9 (EA-25/EA-26)
    - Bool type guard on scaling loop (prevents True*0.4=0.4 bug)
    - diff_bar_range_deg aligned to 25 (matches angular_range_deg)
    - Hub boss OD override: 10 -> 14mm (matches V3 wheel)
    suspension_assembly.py:
    - BOGIE_PIV_Z: hardcoded 45 -> parametric (WHEEL_R + 5)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
    [generate_rover_params.py]
2026-03-24 Self-upgrade: 5 new commands, fix 5 stale commands, expand permissions
    New project commands:
    - /session-start: Load all context at session start
    - /quick-audit: Fast stale count scanner
    - /deploy-scripts: Copy CAD scripts to Fusion 360
    - /stl-check: Validate STL dimensions and bed fit
    - /rod-cutting: Steel rod cutting plan calculator
    Fixed stale commands:
    - skill-guide: Added 5 missing commands, fixed STL count 23→28
    - assembly-order: Replaced deprecated parts with EA-25/26 connectors
    - bom-check: Fixed EA-08 filename, updated parts count and references
    - project-dashboard: Updated CAD script and parts counts
    - deploy-scripts: Added assembly script exclusions
    Orchestrator SKILL.md rewrit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
2026-03-25 NASA-proportioned suspension: rocker pivot Z raised, through-bar diff, wider wheels
    - generate_rover_params.py: wheel width 80→110 (full) / 32→44 (P1),
    body height 200→300 / 80→120, rocker_pivot_z 150→300 / 60→120,
    diff bar_half_span 500→325 / 200→130, through-bar mode (no links)
    - suspension_assembly.py: rewritten with correct bogie pivot Z from
    arm descent angle, through-bar differential, body outline box
    [generate_rover_params.py]
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2026-03-25 Fix component dimensions from datasheet research: N20, ESP32, LiPo
    N20 motor: body 25→15mm, gearbox 12→9mm, total 37→24mm, weight 20→10g
    ESP32 DevKitC-1: PCB length 69→63mm (62.7mm per Espressif DXF)
    LiPo 2S 2200mAh: 70×35×18→86×34×19mm (typical Gens Ace/Turnigy)
    Electronics tray: ESP32 pocket and LiPo cradle resized to match
    [generate_rover_params.py]
2026-03-25 Full project audit: fix 65+ stale refs across 19 files
    CI: seq 0 26 → 0 27 (EA-27 was unchecked)
    Firmware: esp32.ino version comment 0.2.0 → 0.3.0
    CAD: 4 shaft bores 8.0mm → 8.1mm (0.1mm clearance)
    BOM: N20 37→24mm, ESP32 69→63mm, LiPo 70×35×18→86×34×19mm
    Design doc: Ender 3→CTC Bizer, PETG→PLA, 19→9 bearings, EA table
    CLAUDE.md: 33→39 scripts, 29→28 STLs
    README: 27→28 EAs, added EA-25/26/27 to table
    Skills/commands: updated EA counts, STL counts, deprecated parts
    Docs: todo-master PETG→PLA temps, suspension bearing count, etc.
    [esp32.ino]
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2026-03-25 BatchExportAll: 28 STLs generated, 6 stale removed
    - Ran BatchExportAll in Fusion 360 (28/28 components, 27 exports, 0 errors)
    - 10 new STLs: rover_wheel_v3, tube_socket_test, steering_knuckle,
    steering_horn_link, rocker_hub_connector, bogie_pivot_connector,
    front_wheel_connector, middle_wheel_connector, differential_pivot_housing,
    cable_clip
    - 6 stale STLs removed: bogie_arm, rocker_arm_front/rear, diff_bar_adapter,
    rover_wheel (v1), top_deck (unsplit)
    - NOTE: middle_wheel_connector.stl is 684 bytes (needs re-export)
    [body_quadrant_fl.stl, body_quadrant_fr.stl, body_quadrant_rl.stl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]
2026-03-25 Audit fix: 20 stale refs across 8 files, CI branch, EA-00 index
    - CI: branch trigger master→main (matches actual repo branch)
    - rover_assembly.py: N20 37→24mm, ESP32 69→62.7mm, LiPo 70x35x18→86x34x19, bearings 11→9
    - EA-08: N20 body 25+12=37→15+9=24mm, ESP32 69→62.7mm, LiPo dims, battery tray
    - EA-20: N20 dims ×3, bearing count x11→x9, ESP32/LiPo dims, motor envelope
    - EA-01: clarify Phase 1 uses 9 bearings (not 19 which is Phase 2+)
    - EA-00: document index extended to EA-28, purpose line updated, v1.2
    - Design doc: add EA-28 to table, fix version note EA-27→EA-28
    - BOM: N20 37→24mm, O-rings moved to core consumables, add glue stick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
2026-03-25 Fix MiddleWheelConnector and BearingTestPiece scripts, re-export STLs
    - middle_wheel_connector.py: remove broken setByOffset chain (line 85)
    - bearing_test_piece.py: rewrite using extrude instead of revolve,
    use root component instead of subcomponent
    - Re-exported both STLs (middle_wheel_connector was 684B corrupt,
    bearing_test_piece had stale 8.0mm bore, now 8.1mm)
    [bearing_test_piece.stl, middle_wheel_connector.stl]
2026-03-25 CAD redesign: 22 scripts rewritten, helpers module, 29 STLs, assembly V2
    Complete CAD redesign for print-ready Phase 1 Mars Rover parts.
    New files:
    - rover_cad_helpers.py: shared module (bearing seats, tube sockets,
    motor clips, servo pockets, fillets, rounded rects, profile finders)
    - battery_tray.py: 94x42x23mm LiPo cradle with strap slots, XT60 access
    - rover_assembly_v2.py: full assembly visualisation with colour coding
    Redesigned (22 scripts):
    - All parts: rounded-rect bodies (2mm corners), 0.5mm fillets, 0.3mm
    chamfers, proper mating features via shared helpers
    - Consistent hardware interfaces: 608ZZ seats (22.15mm), tube sockets
    (8.2mm), heat-set inserts (4.8mm), M3 through-ho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
    [battery_tray.stl, bearing_test_piece.stl, body_quadrant_fl.stl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]
2026-03-25 EA-29/EA-30, assembly unit fix, full project audit
    - EA-29: CAD redesign documentation (design decisions, 7 errors/fixes, verification)
    - EA-30: Comprehensive CAD testing plan (878 lines, calibration→go/no-go checklist)
    - Fix assembly STL import: CentimeterMeshUnit→MillimeterMeshUnit (10x scale bug)
    - Full audit: 14 files updated, EA count 29→31, STL count 28→29 everywhere
    - Deprecated refs replaced (rocker_arm→tube+connector, diff_bar_adapter→diff_pivot)
    - CI: docs check seq 0 28→30
    - Commands: fusion-export +battery_tray, -differential_link, quick-audit script count
2026-03-25 Deep geometry audit: 46 fixes across 22 CAD scripts
    Rigorous audit beyond constant-checking found 19 CRITICAL + 23 MAJOR
    geometry issues (sketch planes, extrusion directions, assembly fit).
    - 8 sketch plane corrections (features cutting in wrong direction)
    - Steering kinematic chain: horn slot offset, hard stop direction, bore planes
    - Suspension connectors: horizontal→horizontal tube sockets, socket depths
    - ESP32 cradle redesign (board has no mounting holes)
    - Motor pocket/bolt axis fixes on fixed_wheel_mount
    - USE_TPU_TIRE default False (CTC Bizer can't print TPU)
    Major fixes:
    - Wire exit 0.2mm magic numbers → proper WIRE_H values
    - Fuse bracket widened for M3 wall c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
2026-03-26 Fix Z-negation bugs, verify all 23 scripts, re-export STLs
    - Fix XZ/YZ Z-negation bugs in front_wheel_connector (5 fixes) and
    middle_wheel_connector (4 fixes): tube socket plane, bore position,
    grub screw plane/position, servo mount plane type
    - Add flip parameter to make_heat_set_pocket/pair in rover_cad_helpers
    (default True for backwards compat, callers use False when plane is
    at -normal face of body)
    - Fix 5 WARN scripts from prior session: cable_clip, fixed_wheel_mount,
    steering_knuckle, bogie_pivot_connector, body_quadrant
    - All 23 active scripts verified in Fusion 360: single body, correct dims
    - Re-export 23 STLs with PascalCase naming (post-bugfix)
    - Remove 29 old snake_ca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
    [BatteryTray.stl, BearingTestPiece.stl, BodyQuadrant.stl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]
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2026-03-26 Fix assembly paths to PascalCase, add CalibrationTestCard STL, fix docstring
    - rover_assembly_v2.py: all STL paths updated to PascalCase convention,
    added DifferentialLink, fixed FixedWheelMount/SwitchMount paths,
    reduced body/deck to single STL (only 1 variant on disk)
    - steering_bracket.py: docstring fix (heat-set → through-holes)
    - CalibrationTestCard.stl: newly exported (was missing)
    [CalibrationTestCard.stl]
2026-03-26 Rewrite BOM for EA-25/26/27 tube+connector suspension design
    - Replace old monolithic rocker arms, bogie arms, diff bar adapters
    with new tube+connector parts (RockerHubConnector, BogiePivotConnector,
    FrontWheelConnector, MiddleWheelConnector, DifferentialPivotHousing,
    DifferentialLink, CableClip)
    - Fix bearing count: 11 → 9 (no diff bar end bearings in through-bar design)
    - Add SteeringKnuckle, SteeringHornLink, BatteryTray
    - Fix steering bracket dims: 40mm → 25mm height, remove motor clip ref
    - Add M2 horn link hardware (M2x10, nyloc, washers)
    - Add rod cutting plan (9 pieces from 2x 1m rods)
    - Update assembly order for tube+connector workflow
    - BOM v2.0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
2026-03-26 Fix appearance library name in rover_assembly_v2.py
    Changed 'Fusion 360 Appearance Library' to 'Fusion Appearance Library'
    (the correct name in current Fusion 360 versions).
2026-03-26 Fix assembly script: create Design doc (not Part Design)
    Fusion 360 now defaults to Part Design (single component) on Ctrl+N.
    The assembly script needs multi-component support, so it now creates
    its own FusionDesignDocumentType document automatically.
2026-03-26 Rewrite assembly positions from engineering data + add positioning guide
    - DIFF_Z corrected: 60mm → 120mm (body mid-height, not bottom)
    - BOGIE_Z corrected: 40mm → 55mm (from EA-25 Appendix A)
    - Added CONN_X=120mm, CONN_Z=60mm for wheel connector positions
    - Body quadrants: use actual STL dimensions (13.1×22.6cm) for tiling
    - Wheel X signs fixed: -X=left, +X=right (consistent with coord system)
    - Rocker hubs at Z=120mm on diff bar (was incorrectly at Z=60mm)
    - Steering parts positioned relative to connectors (not TRACK_HALF)
    - New doc: assembly-positioning-guide.md with all mating interfaces
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2026-03-26 Add bolt-on wheel mounting system + fix V5 wheel mesh defects
    Bolt-on mounting: 4x M3 on 20mm BCD with 608ZZ bearing decoupling
    - rover_cad_helpers.py: make_heat_set_bcd(), WHEEL_BCD, M3_CLEARANCE
    - middle/front_wheel_connector.py: 2x linear -> 4x BCD bolt pattern
    - fixed_wheel_mount.py: matching through-holes on 20mm BCD
    - add_wheel_bolt_holes.py: manifold3d boolean to add holes to wheel STLs
    - wheel_mounting_assembly.py: assembly builder + alignment verification
    - Hardware viz STLs: M3x10 bolt, 608ZZ bearing, 8mm axle stub
    - Design doc: bolt-on-wheel-mounting-design.md (5 decisions, 5 lessons)
    V5 wheel mesh fix: combined 8 GrabCAD bodies into single solid
    - Opened .f3d, combined hub+spoke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
    [608ZZ_Bearing.stl, 8mm_AxleStub.stl, CuriosityV5_Tread.stl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]
2026-03-31 Housekeeping: rename reference=suspension dir, track reference files
    - Rename cad/reference=suspension/ to cad/reference-suspension/ (fix typo)
    - Update all path references in .gitignore and docs
    - Track Fusion 360 reference wheel files (CuriosityWheelV5)
    - Track assembly screenshot and wheel-assembly docs
    [CuriosityWheelV5_Approved_Baseline.f3d, DIFFSUS2_1.stl, DIFFSUS2_1_04x.stl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]
